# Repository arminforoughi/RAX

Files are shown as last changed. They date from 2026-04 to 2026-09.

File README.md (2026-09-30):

# RAX

**Pick up any object a camera can see, with no training.**

RAX drives a low-cost arm with a wrist camera to an object, lines the object up
between the jaws, squares the grip to it, and grasps. It needs the arm's URDF, a wrist
camera and a detector: a colour, or a text prompt through an open-vocabulary model.
There are no demonstrations, no learned policy and no hand-tuned signs.

On an SO-101 sorting lab tubes into racks, it picks about 80% of the tubes it maps and
stands about half of them upright in a 1 mm-clearance hole. Every run is logged as a
self-labelled episode.

Project page: https://arminforoughi.github.io/RAX/

## How it works

The pick is visual servoing on the arm's own kinematic model. It repeats one short
loop:

1. **See.** The detector gives the object's pixel. The error is how far that pixel is
   from where the fingertips will land, projected into the same image.
2. **Measure.** A small test turn of the base shows how many pixels the object moves
   per degree, so the correction is `error / gain`. No sign or scale is assumed; on the
   SO-101 the base turns the opposite way to intuition, and a hard-coded sign drove it
   steadily away from the object.
3. **Solve.** Every move is inverse kinematics on the URDF with the hand's angle held,
   started from several poses, keeping the solution nearest the current one.

In order: LOOK, PROBE, AIM, APPROACH, HOVER, STAND, TRIM, TWIST, DESCEND, GRASP, LIFT.
The image only ever turns the base. The reach comes from casting the pixel onto the
table, and then from a measured pixels-per-metre once the hand is over the object. The
last centimetres are a straight vertical drop, so the fingers never sweep the object
away. The grip is judged by where the jaws stop: shut means empty, stopped short means
holding, and too wide means it took two.

## Use it

```python
from rax.pick import pick, place, scan, ColourTarget, PromptTarget, TOP, SIDE

target = PromptTarget(prompt="cup", grasp_z=0.04)      # or ColourTarget(colours=("red",))
for obj in scan(arm, target):                          # map the table once
    pick(arm, target, near_xy=(obj.x, obj.y), grasp=TOP)   # TOP: 90deg down, SIDE: level
    place(arm, (0.20, -0.15), release_z=0.08, pitch=0, roll=90)
```

`arm` is anything that implements [`rax.pick.arm.Arm`](src/rax/pick/arm.py), about
fifteen methods: joints, FK, IK, a camera frame, pixel-to-table and back, the gripper.
[`rax.robots.so101.So101`](src/rax/robots/so101.py) is the real SO-101 with a wrist
OAK-D.

### No robot? Run the simulator

```
pip install -e .
python examples/pick_demo.py
```

[`rax.pick.sim.SimArm`](src/rax/pick/sim.py) uses the SO-101's real URDF, IK and camera
model, with a drawn image and a simple gripper, so the whole loop runs closed on a
laptop. It tests the logic, not the camera.

### The tube-sorting rig

```
pip install -e ".[robot]"
python examples/tube_sorting/server.py --port COM4      # UI on http://127.0.0.1:8486
```

It maps the mat with one wrist-camera sweep, picks each tube, stands it up and drops it
into its colour's rack. An optional overhead camera lines the tube up over the hole and
checks that it went in. See [`examples/tube_sorting`](examples/tube_sorting).

## Layout

```
src/rax/pick/         the method: pick, place, scan, targets, simulator, episodes
src/rax/kinematics/   URDF forward kinematics, pitch-holding IK, smooth moves
src/rax/perception/   camera model (pixels <-> base frame), tube-cap detector
src/rax/robots/       SO-101 driver, profile and URDF
examples/             pick_demo.py (simulator), tube_sorting/ (the real rig)
tests/                pytest; no hardware needed
```

## License

See [LICENSE](LICENSE).

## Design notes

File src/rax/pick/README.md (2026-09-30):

# rax.pick

Pick up any object a wrist camera can detect, with no training and no hand-tuned
signs. It needs the arm's URDF, a wrist camera, and a detector for the object.

```python
from rax.pick import pick, place, scan, PromptTarget, TOP, SIDE

cup = PromptTarget(prompt="cup", grasp_z=0.04)        # open-vocabulary, no training
for obj in scan(arm, cup):                            # map the table once
    pick(arm, cup, near_xy=(obj.x, obj.y), grasp=SIDE)
    place(arm, (0.20, -0.15), release_z=0.06, pitch=0, roll=0)
```

## How it works

The pick is visual servoing on the arm's own model:

1. **See.** The detector gives a pixel. The error is how far that pixel is from where
   the fingertips will land, projected into the same image.
2. **Measure.** A small test turn of the base shows how many pixels the object moves
   per degree. Dividing the error by that gives the correction, so no sign or scale is
   ever assumed.
3. **Solve.** Every move is inverse kinematics on the URDF with the hand's angle held,
   started from several poses, keeping the solution nearest the current one.

The stages are LOOK, PROBE, AIM, APPROACH, HOVER, STAND, TRIM, TWIST, DESCEND, GRASP
and LIFT (see `pick.py`). The image only ever turns the base. The reach comes from
casting the pixel onto the table, and then from a measured pixels-per-metre once the
hand is over the object.

**Grasp angle.** `TOP` comes straight down (pitch 90) and rolls the wrist square to the
object's long axis. `SIDE` keeps the hand level (pitch 0) and reaches in horizontally.

**Grip check.** The grip is judged by where the jaws stop: closed means empty, stopped
short means holding, and too wide means it took two.

## Plugging in

- **A robot:** implement `rax.pick.arm.Arm`, about fifteen methods covering joints, FK,
  IK, camera frame, cast and project, gripper, and log.
  `rax.robots.so101.So101` does it for the SO-101 with a wrist OAK-D.
- **An object:** subclass `Target` and write `detect()`. `ColourTarget` finds HSV blobs
  (test-tube caps). `PromptTarget` uses YOLO-World with a text prompt.

## Try it without a robot

```
python examples/pick_demo.py
```

`rax.pick.sim.SimArm` is the SO-101's real kinematics and camera model with a drawn
image and a simple gripper, so the full loop runs closed on a laptop. The sim tests the
logic, not the camera: a real run is the only real test.

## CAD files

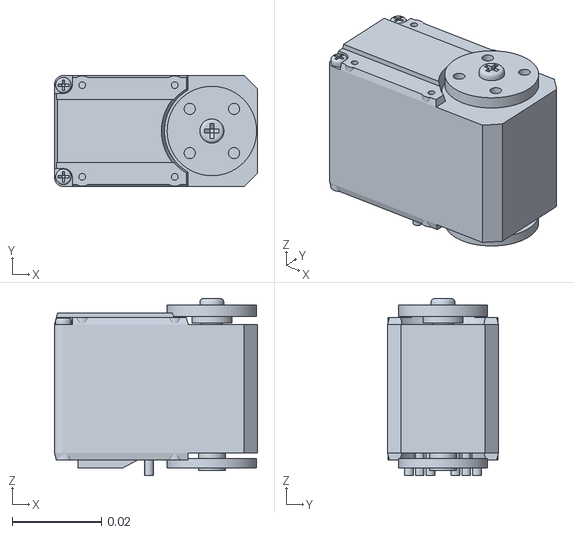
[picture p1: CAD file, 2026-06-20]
src/rax/robots/so101_model/assets/sts3215_03a_v1.stl
0.0454 x 0.0248 x 0.0396

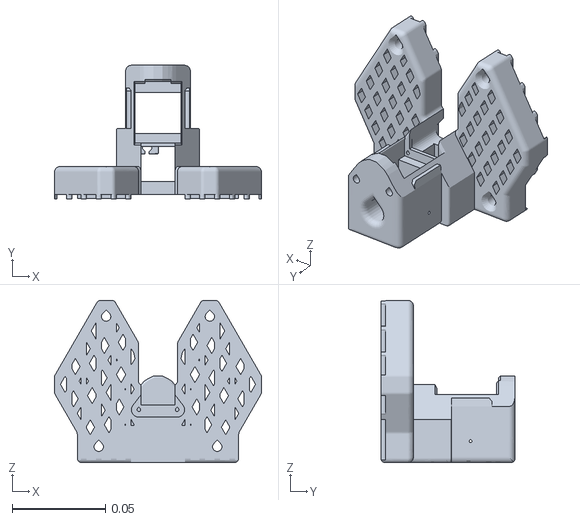
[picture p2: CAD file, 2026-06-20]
src/rax/robots/so101_model/assets/base_so101_v2.stl
0.111 x 0.072 x 0.087

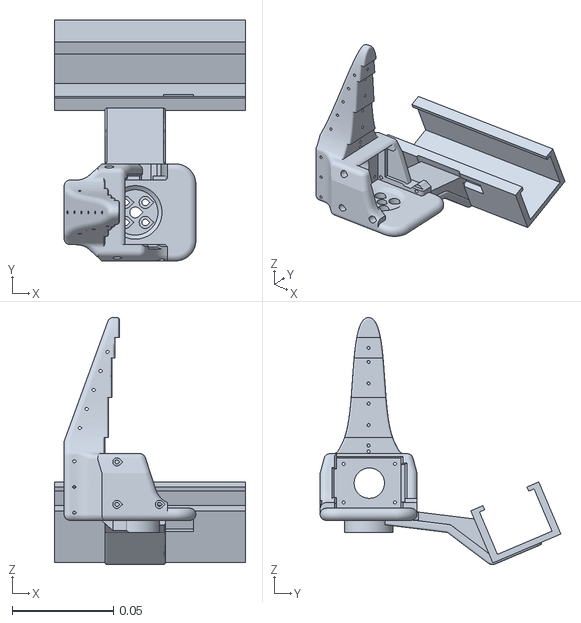
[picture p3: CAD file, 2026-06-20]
src/rax/robots/so101_model/assets/Wrist_Roll_D405_Holder - SO_ARM100_Wrist_Roll_2 v4.stl
0.0946 x 0.119 x 0.122

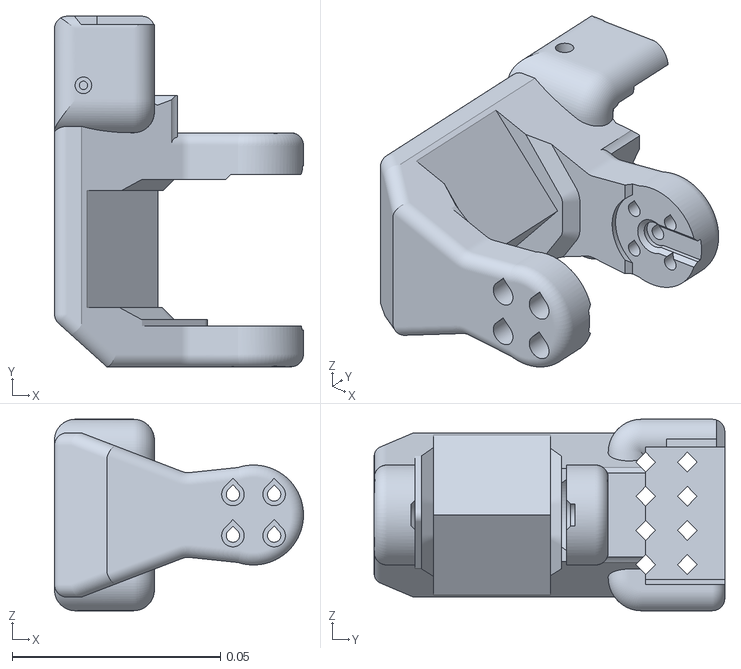
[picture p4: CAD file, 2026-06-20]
src/rax/robots/so101_model/assets/rotation_pitch_so101_v1.stl
0.0598 x 0.0842 x 0.046

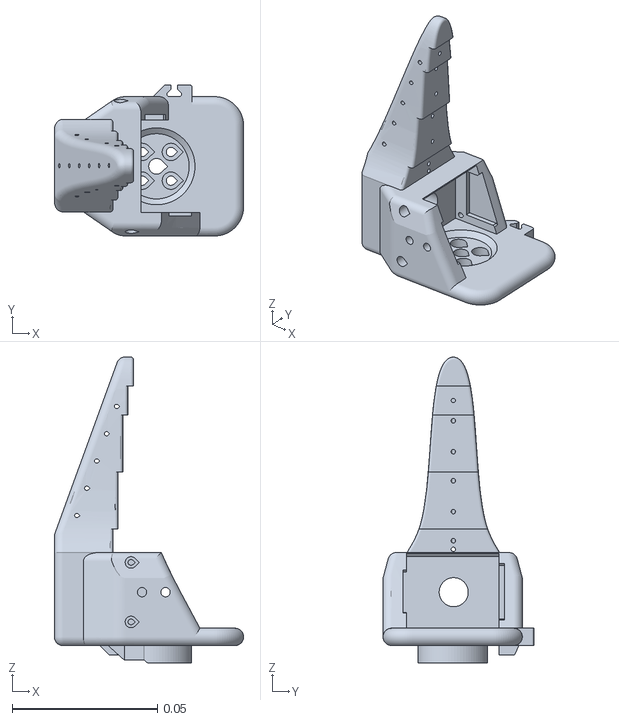
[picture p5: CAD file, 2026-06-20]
src/rax/robots/so101_model/assets/wrist_roll_follower_so101_v1.stl
0.0652 x 0.052 x 0.105

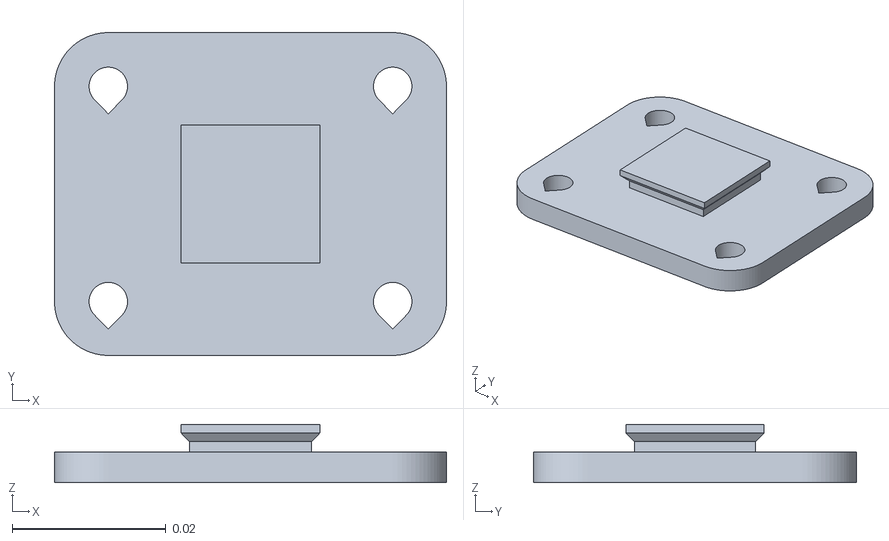
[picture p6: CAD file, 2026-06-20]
src/rax/robots/so101_model/assets/waveshare_mounting_plate_so101_v2.stl
0.051 x 0.042 x 0.0076

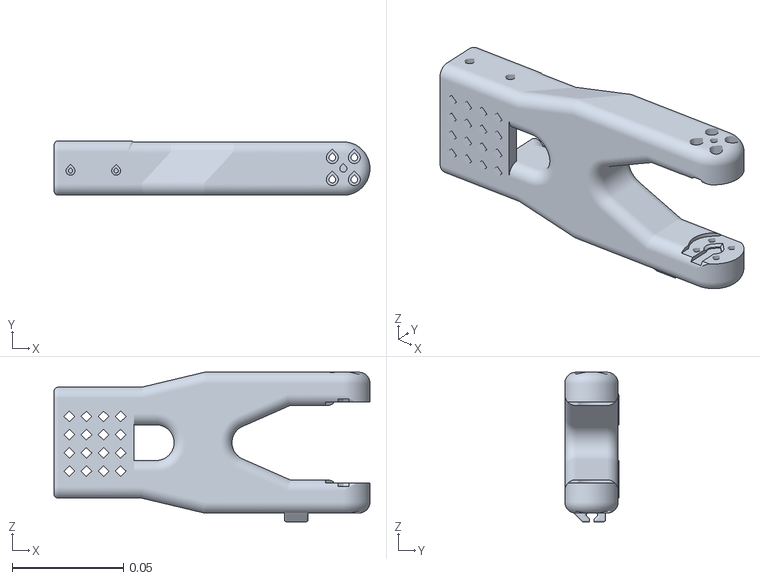
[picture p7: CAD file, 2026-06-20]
src/rax/robots/so101_model/assets/upper_arm_so101_v1.stl
0.142 x 0.0245 x 0.0673

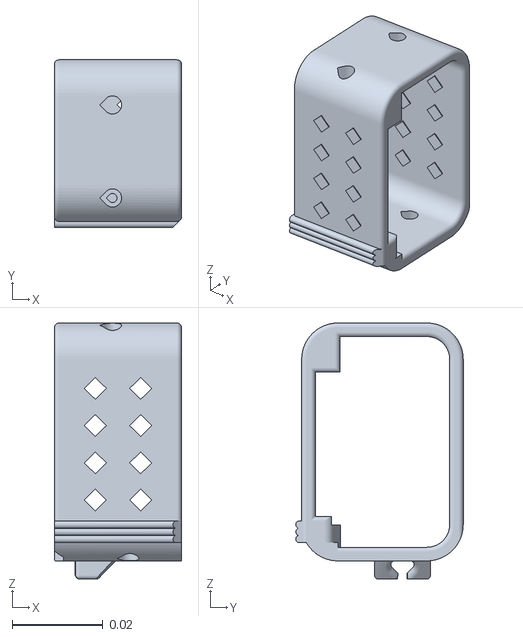
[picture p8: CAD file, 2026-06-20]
src/rax/robots/so101_model/assets/motor_holder_so101_wrist_v1.stl
0.028 x 0.0369 x 0.0564

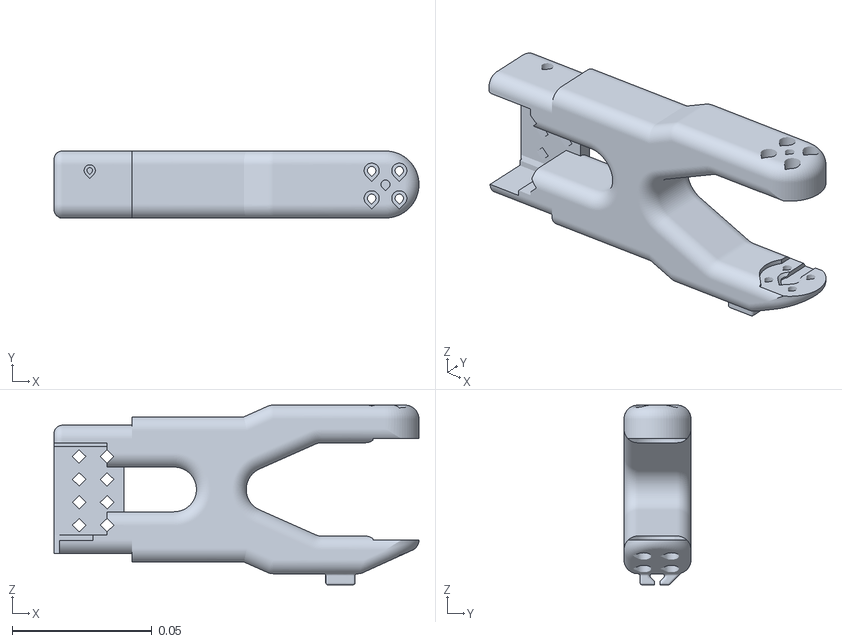
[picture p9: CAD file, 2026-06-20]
src/rax/robots/so101_model/assets/under_arm_so101_v1.stl
0.131 x 0.024 x 0.0644

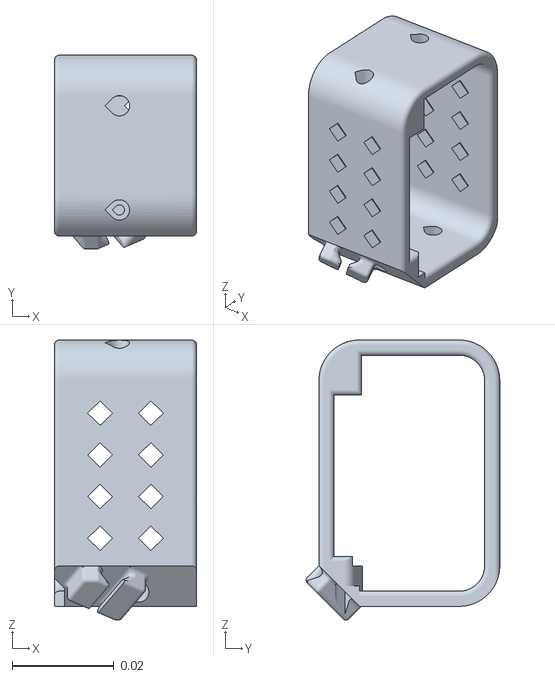
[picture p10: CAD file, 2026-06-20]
src/rax/robots/so101_model/assets/motor_holder_so101_base_v1.stl
0.028 x 0.0381 x 0.0551

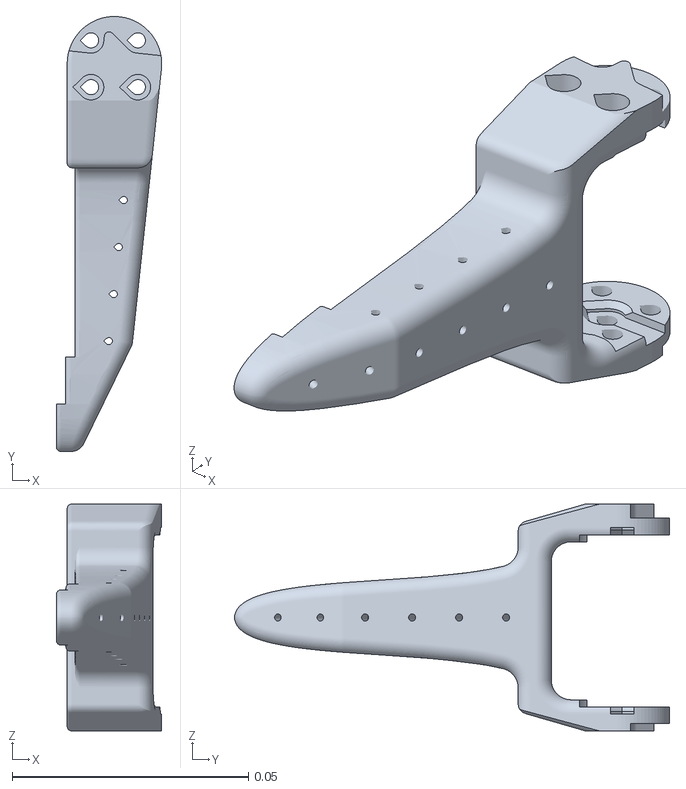
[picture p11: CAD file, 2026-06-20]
src/rax/robots/so101_model/assets/moving_jaw_so101_v1.stl
0.0223 x 0.092 x 0.048

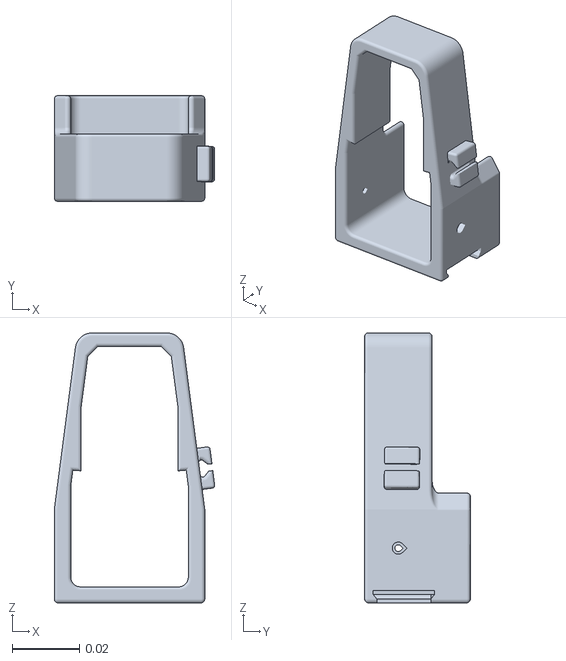
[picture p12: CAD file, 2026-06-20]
src/rax/robots/so101_model/assets/base_motor_holder_so101_v1.stl
0.0476 x 0.0314 x 0.0802

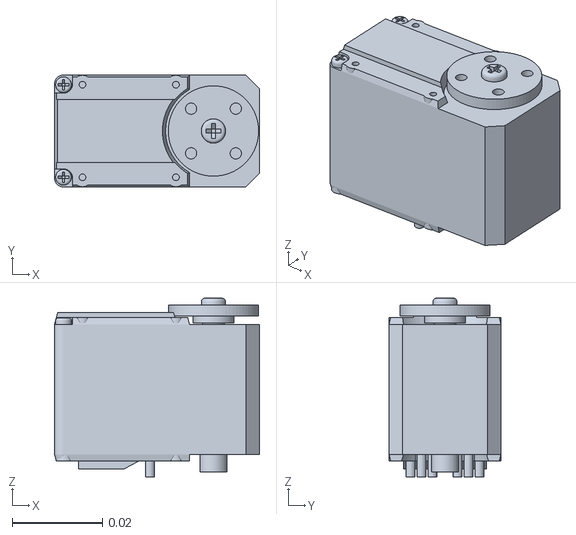
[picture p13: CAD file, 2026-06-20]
src/rax/robots/so101_model/assets/sts3215_03a_no_horn_v1.stl
0.0454 x 0.0248 x 0.0396

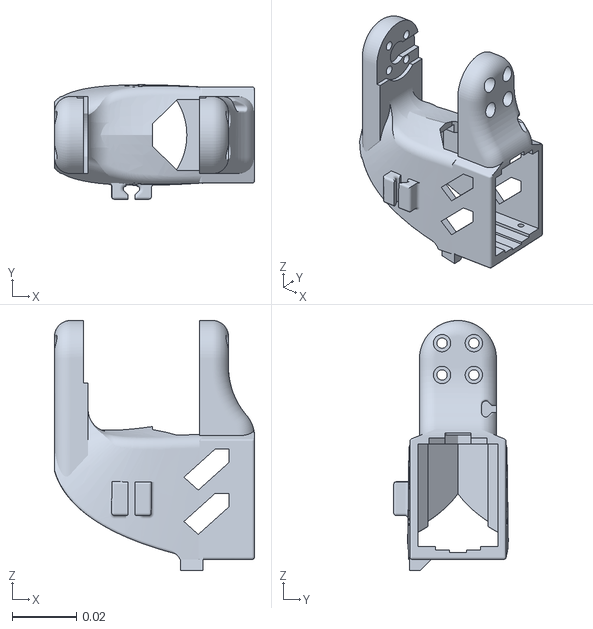
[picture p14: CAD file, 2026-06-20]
src/rax/robots/so101_model/assets/wrist_roll_pitch_so101_v2.stl
0.0623 x 0.0357 x 0.0778

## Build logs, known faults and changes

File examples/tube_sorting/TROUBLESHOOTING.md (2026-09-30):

# Mission server: the rig will not connect

Read this before touching a cable. In Sep 2026 this cost about a week, and the
whole time the hardware was fine.

## The symptom

`run_server.ps1` starts, the arm connects, and then the server dies:

```
overload cleared - 1:0x00 2:0x00 3:0x00 4:0x00 5:0x00 6:0x00   <- arm is FINE
connecting robot + camera...
WARNING [OAK-D] USB3 connect attempt 1 failed (Failed to find device after booting,
                error message: X_LINK_DEVICE_NOT_FOUND)
... 6 attempts, 3x USB3 then 3x USB2, ~17s each ...
RuntimeError: Failed to find device after booting, error message: X_LINK_DEVICE_NOT_FOUND
```

`X_LINK_DEVICE_NOT_FOUND` reads like "no camera attached". It is not. It means
the camera booted and then vanished before depthai could reopen it.

## Why it is so easy to misdiagnose

**The OAK-D has two USB identities.** This is the single most important fact here.

| id | name | when |
|---|---|---|
| `03E7:2485` | Movidius MyriadX | while idle, unbooted (bootloader) |
| `03E7:F63B` | Luxonis Device | after depthai uploads firmware |

`dai.Device()` boots the camera from `2485` into `F63B`, and `F63B` must
re-enumerate as a fresh USB device before depthai can open it. So a fault that
only affects `F63B` is **invisible at rest**: Device Manager shows a healthy
`Movidius MyriadX`, `getAllAvailableDevices()` returns the device with
`state=X_LINK_UNBOOTED, status=X_LINK_SUCCESS`, and everything looks correct
right up until you try to use it.

It also means **the camera works perfectly on another machine.** Both faults
below live in this PC's registry, keyed to the device. They do not travel with
the hardware. A successful test on a Mac tells you nothing about them - it only
rules out the camera, which was never the problem.

## The two root causes

### 1. The booted identity was disabled

`ConfigFlags=1` (`CONFIGFLAG_DISABLED`) on the `F63B` key. Windows disabled the
device the instant it enumerated. Watching the device tree once per second
during a connect attempt showed the whole cycle:

```
 0s  2485 bootloader   OK/present
 2s  2485 disappears                  <- device resets to boot
 3s  F63B appears      Error/present  <- booted, enumerated, then DISABLED
 8s  F63B still        Error/present
 9s  F63B gone, 2485 back             <- gives up, reverts to bootloader
```

The boot works every time. The device is disabled on arrival.

### 2. usbipd had the devices bound

Both the camera and the arm showed `STATE=Shared` in `usbipd list`, with the
OAK-D on the generic Microsoft `WINUSB` driver rather than a Luxonis one.
Binding hands a device toward WSL and swaps its driver.

Worse, these were **persisted** bindings, which re-apply themselves on every
replug. That is the mechanism that made the fault come back every single time
the camera was plugged in, no matter what was done to it.

## Diagnose

None of this needs admin:

```powershell
# is the booted identity disabled?  1 = CONFIGFLAG_DISABLED, 0 = healthy
(Get-ItemProperty 'HKLM:\SYSTEM\CurrentControlSet\Enum\USB\VID_03E7&PID_F63B\19443010F15FF81200' `
  -Name ConfigFlags).ConfigFlags

# is anything holding the devices?  look for STATE=Shared, and the Persisted list
usbipd list

# does the arm's port exist at all?
[System.IO.Ports.SerialPort]::getportnames()

# does the camera boot outside the server?  isolates depthai from lerobot/Flask
python -c "import depthai as dai; d=dai.Device(); print('OK', d.getUsbSpeed())"
```

To watch the boot cycle live, poll during a connect attempt:

```powershell
Get-PnpDevice | Where-Object { $_.InstanceId -match 'VID_03E7' } |
  Select-Object Status, Present, InstanceId
```

Note the busid in `usbipd list` **changes on every replug** (`5-3` one day, `5-2`
the next). Always read it fresh; a stale busid gives
`error: There is no device with busid`.

## Fix

Both need an **administrator** PowerShell. `Enable-PnpDevice` reports
`Generic failure` here because the `F63B` device is only present for ~6 seconds
during a boot attempt; the registry write is what actually lands.

```powershell
# 1. clear the disable flag
Set-ItemProperty 'HKLM:\SYSTEM\CurrentControlSet\Enum\USB\VID_03E7&PID_F63B\19443010F15FF81200' `
  -Name ConfigFlags -Value 0 -Type DWord

# 2. release both devices from usbipd (read busids fresh from 'usbipd list')
usbipd unbind --busid <camera-busid>
usbipd unbind --busid <arm-busid>
```

Then **unplug and replug the camera** so it re-enumerates with the flag clear.

`fix_oakd.ps1` (next to this file) does all of this in one pass, including taking ownership
of the `Enum` key if it refuses the write, and logs what it did.

Verify: `usbipd list` should show the rig as `Not shared` and, critically, the
`Persisted` section should no longer list the Movidius or the CH343. If a
persisted entry survives, the fault will return on the next replug.

## Prevention

`run_server.ps1` now preflights all three conditions before launching and
refuses to start with the exact remediation command, rather than dying ~40s
later inside `cam.connect()` with an error that reads like dead hardware.
`-SkipPreflight` bypasses it if a check ever misfires.

## Things that are NOT the cause

Ruled out during the investigation, recorded so nobody re-runs them:

- **Hubs / power.** Both devices sit behind two chained Genesys Logic hubs
  (`05E3:0610`), which is a genuinely plausible cause of exactly this failure -
  but the boot trace disproved it. The device re-enumerates cleanly every time.
- **The cable, the port, the camera.** It works on other machines.
- **depthai version.** 3.7.1, unchanged since Jun 2026, working before and after.
- **Process contention.** No Python process was running during the failures.
- **The server, lerobot, Flask.** Plain `dai.Device()` fails identically.
- **WSL holding the device.** Ubuntu was stopped, and no `/dev/ttyACM*` or
  `/dev/ttyUSB*` existed inside it.

## Related: the arm

The arm (`1A86:55D3`, CH343 -> COM4) fails differently and independently. If
`[System.IO.Ports.SerialPort]::getportnames()` returns **nothing**, the adapter
has not enumerated at all - that is a cable or port fault, and no config change
will help. Note `HKLM:\HARDWARE\DEVICEMAP\SERIALCOMM` does not exist when no
serial device is present; Windows creates it on demand, so a missing key means
"none attached", not "broken".

Do not confuse the two `Realtek RealManage COM1/COM2` devices for usable serial
ports. They are class `MultiFunction`, part of the board's IPMI/out-of-band
management, and they are always present.

## Related: the overhead camera

The server reads an optional overhead MJPEG camera (a CamSurv server) set by
`RAX_CAMSURV_URL`, `RAX_CAMSURV_PASSWORD` and `RAX_CAMSURV_STREAM`. Without it the drop
goes to each hole's estimated position and is not verified; the robot side is
unaffected. If the top view is blank, check whether anything is listening on that URL.

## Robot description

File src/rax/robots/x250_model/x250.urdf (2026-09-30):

<?xml version="1.0"?>
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
<robot name="x250">

  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

  <link name="base_link">
    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
  </link>

  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
  <link name="shoulder_link">
    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
  </link>

  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
  <link name="upper_arm_link">
    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
  </link>

  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
  <link name="forearm_link">
    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
  </link>

  <link name="wrist_link">
    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
  </link>

  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
  <link name="gripper_link">
    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
  </link>

  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
  <link name="gripper_frame_link"/>

  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
  <link name="left_finger_link">
    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
  </link>
  <link name="right_finger_link">
    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
  </link>

  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

  <joint name="base" type="revolute">
    <parent link="base_link"/>
    <child link="shoulder_link"/>
    <origin xyz="0 0 0.079" rpy="0 0 0"/>
    <axis xyz="0 0 1"/>
    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
    <limit lower="-3.059165" upper="3.222488" effort="10" velocity="3.0"/>
  </joint>

  <joint name="shoulder_2" type="revolute">
    <parent link="shoulder_link"/>
    <child link="upper_arm_link"/>
    <origin xyz="0 0 0.040" rpy="0 0 0"/>
    <axis xyz="0 1 0"/>
    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
    <limit lower="-1.840924" upper="1.504690" effort="10" velocity="3.0"/>
  </joint>

  <joint name="elbow" type="revolute">
    <parent link="upper_arm_link"/>
    <child link="forearm_link"/>
    <origin xyz="0.050 0 0.250" rpy="0 0 0"/>
    <axis xyz="0 1 0"/>
    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
    <limit lower="-0.944656" upper="0.936005" effort="10" velocity="3.0"/>
  </joint>

  <joint name="wrist" type="revolute">
    <parent link="forearm_link"/>
    <child link="wrist_link"/>
    <origin xyz="0.175 0 0" rpy="0 0 0"/>
    <axis xyz="0 1 0"/>
    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
    <limit lower="-1.641396" upper="4.640256" effort="10" velocity="3.0"/>
  </joint>

  <joint name="tool" type="revolute">
    <parent link="wrist_link"/>
    <child link="gripper_link"/>
    <origin xyz="0.075 0 0" rpy="0 0 0"/>
    <axis xyz="1 0 0"/>
    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
    <limit lower="-2.622260" upper="1.152868" effort="10" velocity="3.0"/>
  </joint>

  <joint name="ee_fixed" type="fixed">
    <parent link="gripper_link"/>
    <child link="gripper_frame_link"/>
    <origin xyz="0.080 0 0" rpy="0 0 0"/>
  </joint>

  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
  <joint name="gripper_left" type="prismatic">
    <parent link="gripper_link"/>
    <child link="left_finger_link"/>
    <origin xyz="0.050 0.013 0" rpy="0 0 0"/>
    <axis xyz="0 1 0"/>
    <limit lower="0.0" upper="0.022" effort="10" velocity="0.2"/>
  </joint>
  <joint name="gripper_right" type="prismatic">
    <parent link="gripper_link"/>
    <child link="right_finger_link"/>
    <origin xyz="0.050 -0.013 0" rpy="0 0 0"/>
    <axis xyz="0 -1 0"/>
    <limit lower="0.0" upper="0.022" effort="10" velocity="0.2"/>
  </joint>

</robot>

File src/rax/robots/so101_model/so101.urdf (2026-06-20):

<?xml version="1.0" encoding="utf-8"?>
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
<robot name="so101_new_calib">

  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
  <link name="base_link">
    <inertial>
      <origin xyz="0.0137179 -5.19711e-05 0.0334843" rpy="0 0 0"/>
      <mass value="0.147"/>
      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
    </inertial>
    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
  </link>

  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
  <link name="shoulder_link">
    <inertial>
      <origin xyz="-0.0307604 -1.66727e-05 -0.0252713" rpy="0 0 0"/>
      <mass value="0.100006"/>
      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
    </inertial>
    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
  </link>

  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
  <link name="upper_arm_link">
    <inertial>
      <origin xyz="-0.0898471 -0.00838224 0.0184089" rpy="0 0 0"/>
      <mass value="0.103"/>
      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
    </inertial>
    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
  </link>

  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
  <link name="lower_arm_link">
    <inertial>
      <origin xyz="-0.0980701 0.00324376 0.0182831" rpy="0 0 0"/>
      <mass value="0.104"/>
      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
    </inertial>
    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
  </link>

  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
  <link name="wrist_link">
    <inertial>
      <origin xyz="-0.000103312 -0.0386143 0.0281156" rpy="0 0 0"/>
      <mass value="0.079"/>
      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
    </inertial>
    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
  </link>

  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
  <link name="gripper_link">
    <inertial>
      <origin xyz="0.000213627 0.000245138 -0.025187" rpy="0 0 0"/>
      <mass value="0.087"/>
      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
    </inertial>
    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
  </link>

  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
  <link name="gripper_frame_link">
    <origin xyz="0 0 0" rpy="0 -0 0"/>
    <inertial>
      <origin xyz="0 0 0" rpy="0 0 0"/>
      <mass value="1e-9"/>
      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
    </inertial>
  </link>

  <joint name="gripper_frame_joint" type="fixed">
    <origin xyz="-0.0079 -0.000218121 -0.0981274" rpy="0 3.14159 0"/>
    <parent link="gripper_link"/>
    <child link="gripper_frame_link"/>
    <axis xyz="0 0 0"/>
  </joint>

  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
  <link name="moving_jaw_so101_v1_link">
    <inertial>
      <origin xyz="-0.00157495 -0.0300244 0.0192755" rpy="0 0 0"/>
      <mass value="0.012"/>
      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
    </inertial>
    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
  </link>

  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
  <joint name="gripper" type="revolute">
    <origin xyz="0.0202 0.0188 -0.0234" rpy="1.5708 -5.24284e-08 -1.41553e-15"/>
    <parent link="gripper_link"/>
    <child link="moving_jaw_so101_v1_link"/>
    <axis xyz="0 0 1"/>
    <limit effort="10" velocity="10" lower="-0.174533" upper="1.74533"/>
  </joint>

  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
  <joint name="wrist_roll" type="revolute">
    <origin xyz="5.55112e-17 -0.0611 0.0181" rpy="1.5708 0.0486795 3.14159"/>
    <parent link="wrist_link"/>
    <child link="gripper_link"/>
    <axis xyz="0 0 1"/>
    <limit effort="10" velocity="10" lower="-2.74385" upper="2.84121"/>
  </joint>

  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
  <joint name="wrist_flex" type="revolute">
    <origin xyz="-0.1349 0.0052 3.62355e-17" rpy="4.02456e-15 8.67362e-16 -1.5708"/>
    <parent link="lower_arm_link"/>
    <child link="wrist_link"/>
    <axis xyz="0 0 1"/>
    <limit effort="10" velocity="10" lower="-1.65806" upper="1.65806"/>
  </joint>

  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
  <joint name="elbow_flex" type="revolute">
    <origin xyz="-0.11257 -0.028 1.73763e-16" rpy="-3.63608e-16 8.74301e-16 1.5708"/>
    <parent link="upper_arm_link"/>
    <child link="lower_arm_link"/>
    <axis xyz="0 0 1"/>
    <limit effort="10" velocity="10" lower="-1.69" upper="1.69"/>
  </joint>

  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
  <joint name="shoulder_lift" type="revolute">
    <origin xyz="-0.0303992 -0.0182778 -0.0542" rpy="-1.5708 -1.5708 0"/>
    <parent link="shoulder_link"/>
    <child link="upper_arm_link"/>
    <axis xyz="0 0 1"/>
    <limit effort="10" velocity="10" lower="-1.74533" upper="1.74533"/>
  </joint>

  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
  <joint name="shoulder_pan" type="revolute">
    <origin xyz="0.0388353 -8.97657e-09 0.0624" rpy="3.14159 4.18253e-17 -3.14159"/>
    <parent link="base_link"/>
    <child link="shoulder_link"/>
    <axis xyz="0 0 1"/>
    <limit effort="10" velocity="10" lower="-1.91986" upper="1.91986"/>
  </joint>

  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 

</robot>

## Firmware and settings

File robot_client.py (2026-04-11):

#!/usr/bin/env python3
"""
Robot Client — runs on the Booster K1 robot.
Streams camera + depth + audio to a remote server via WebSocket.
Receives and executes control commands.

Usage:
    python3 robot_client.py eth0 --server ws://YOUR_PC_IP:9090
"""

import os
import sys
import glob
import asyncio
import threading
import time
import argparse
import json
import struct
import zlib

import numpy as np
import cv2
try:
    import pyaudio
except ImportError:
    import pyaudio_compat as pyaudio
import websockets

import rclpy
from rclpy.node import Node
from sensor_msgs.msg import Image, CompressedImage
from cv_bridge import CvBridge

from booster_robotics_sdk_python import (
    B1LocoClient, ChannelFactory, RobotMode, B1HandIndex, B1HandAction,
    Position, Orientation, Posture,
)

SEND_SAMPLE_RATE = 16000
RECV_SAMPLE_RATE = 24000
AUDIO_CHANNELS = 1
AUDIO_FORMAT = pyaudio.paInt16
AUDIO_CHUNK = 1024

# Binary message type prefixes (robot -> server stream)
MSG_VIDEO = 0x01
MSG_DEPTH = 0x02
MSG_AUDIO_IN = 0x03

# Optional low-level joint API (fight guard / jabs use real elbow/shoulder angles).
_LOWLEVEL = None
try:
    import booster_robotics_sdk_python as _br_sdk
    _b1 = getattr(_br_sdk, 'b1', None)
    _LOWLEVEL = {
        'B1LowStateSubscriber': getattr(_br_sdk, 'B1LowStateSubscriber', None),
        'B1LowCmdPublisher': getattr(_br_sdk, 'B1LowCmdPublisher', None),
        'LowCmd': getattr(_br_sdk, 'LowCmd', None),
        'MotorCmd': getattr(_br_sdk, 'MotorCmd', None),
        'CmdType': getattr(_br_sdk, 'CmdType', None),
        'JointIndex': getattr(_br_sdk, 'JointIndex', None),
        'kTopicJointCtrl': getattr(_br_sdk, 'kTopicJointCtrl', None) or (
            getattr(_b1, 'kTopicJointCtrl', None) if _b1 else None
        ),
        'kJointCnt': getattr(_br_sdk, 'kJointCnt', None),
    }
    if not all((_LOWLEVEL['B1LowStateSubscriber'], _LOWLEVEL['B1LowCmdPublisher'],
                _LOWLEVEL['LowCmd'], _LOWLEVEL['MotorCmd'], _LOWLEVEL['JointIndex'])):
        _LOWLEVEL = None
except ImportError:
    _LOWLEVEL = None


def _prepend_booster_interface_paths():
    """Find booster_interface Python bindings without sourcing setup.bash (systemd / wrong cwd)."""
    added = []
    seen = set(sys.path)

    def _add(sp):
        sp = os.path.abspath(sp)
        if not os.path.isdir(sp) or sp in seen:
            return
        bi = os.path.join(sp, 'booster_interface')
        if not os.path.isdir(bi):
            return
        sys.path.insert(0, sp)
        seen.add(sp)
        added.append(sp)

    roots = []
    for key in ('BOOSTER_ROS2_INSTALL', 'COLCON_PREFIX_PATH'):
        raw = os.environ.get(key, '')
        for part in raw.split(os.pathsep):
            part = part.strip()
            if not part:
                continue
            roots.append(part)
            if not part.rstrip(os.sep).endswith('install') and os.path.isdir(os.path.join(part, 'install')):
                roots.append(os.path.join(part, 'install'))

    roots.extend([
        '/opt/booster/BoosterRos2Interface/install',
        '/opt/booster/ros2_ws/install',
    ])

    for base in roots:
        if not base or not os.path.isdir(base):
            continue
        pattern = os.path.join(base, 'booster_interface', 'lib', 'python*', 'site-packages')
        for sp in glob.glob(pattern):
            _add(sp)

    for prefix in os.environ.get('AMENT_PREFIX_PATH', '').split(os.pathsep):
        prefix = prefix.strip()
        if not prefix or not os.path.isdir(prefix):
            continue
        for sp in glob.glob(os.path.join(prefix, 'lib', 'python*', 'site-packages')):
            _add(sp)

    # Shallow walk: install layout on K1 often differs from the paths above.
    for root, max_depth in (
        ('/opt/booster', 10),
        (os.path.expanduser('~/booster_ws/install'), 8),
        (os.path.expanduser('~/ros2_ws/install'), 8),
    ):
        if not root or not os.path.isdir(root):
            continue
        root = os.path.abspath(root)
        for dirpath, dirnames, _ in os.walk(root):
            depth = dirpath[len(root) :].count(os.sep)
            if depth > max_depth:
                dirnames[:] = []
                continue
            if os.path.basename(dirpath) == 'site-packages' and os.path.isdir(
                os.path.join(dirpath, 'booster_interface')
            ):
                _add(dirpath)

    return added


def _ji(joint_index_enum, name):
    """Safe JointIndex lookup (int value for motor_cmd index)."""
    if joint_index_enum is None:
        return None
    j = getattr(joint_index_enum, name, None)
    if j is None:
        return None
    try:
        return int(j)
    except (TypeError, ValueError):
        return j


def _joint_index_enum():
    """JointIndex for arm mapping (SDK may expose it even when DDS lowcmd is unused)."""
    if _LOWLEVEL and _LOWLEVEL.get('JointIndex'):
        return _LOWLEVEL['JointIndex']
    try:
        import booster_robotics_sdk_python as _br
        return getattr(_br, 'JointIndex', None)
    except ImportError:
        return None


class FightLowCmdController:
    """LowCmd fight control: ROS2 joint_ctrl + /low_state (Booster deploy), else DDS LowCmd."""

    def __init__(self, loco_client: B1LocoClient, sdk_lock: threading.Lock, ros_node=None):
        self.client = loco_client
        self.sdk_lock = sdk_lock
        self._ros_node = ros_node
        self._use_ros = False
        self._q = None
        self._q_lock = threading.Lock()
        self._pub = None
        self._sub = None
        self._n = 0
        self._hold = threading.Event()
        self._hold_thread = None
        self._hz = 50.0
        self._kp_default = 55.0
        self._kd_default = 2.2
        self._kp_arm = 72.0
        self._kd_arm = 2.8
        self._guard_ov = {}
        self._overlay = {}
        self._overlay_lock = threading.Lock()

    @staticmethod
    def _booster_ros_msgs_ok():
        try:
            from booster_interface.msg import LowCmd  # noqa: F401
            return True
        except ImportError:
            return False

    @property
    def available(self):
        # Always try if we have the streaming node (it will import booster_interface on demand).
        if self._ros_node is not None:
            return True
        return self._booster_ros_msgs_ok() or _LOWLEVEL is not None

    def set_ros_node(self, node):
        self._ros_node = node

    def _on_state(self, msg):
        try:
            serial = msg.motor_state_serial
            with self._q_lock:
                self._q = [float(m.q) for m in serial]
                self._n = len(self._q)
        except Exception:
            pass

    def _get_base_q(self):
        if self._use_ros and self._ros_node is not None:
            q = self._ros_node.booster_joint_snapshot()
            if q and len(q) == self._n:
                return q
            return None
        with self._q_lock:
            return list(self._q) if self._q else None

    def _ensure_io(self):
        if self._n > 0 and (self._use_ros or self._pub is not None):
            return True

        if self._ros_node is not None:
            if self._ros_node.ensure_booster_fight_bridge():
                t0 = time.time()
                while time.time() - t0 < 3.0:
                    n = self._ros_node.booster_num_joints()
                    if n > 0:
                        break
                    time.sleep(0.02)
                n = self._ros_node.booster_num_joints()
                if n <= 0:
                    print('[FightLowCmd] /low_state not received (check Booster ROS2 bridge)')
                else:
                    self._ros_node.booster_init_lowcmd_motors(n)
                    if self._ros_node.booster_wait_joint_ctrl_subscriber(25.0):
                        self._n = n
                        self._use_ros = True
                        print('[FightLowCmd] ROS2 joint_ctrl + /low_state (same as booster_deploy / teleop stack)')
                        return True
                    print('[FightLowCmd] No subscriber on joint_ctrl yet (motion stack listening?)')
                    self._n = 0

        if _LOWLEVEL is None:
            return False
        L = _LOWLEVEL
        topic = L['kTopicJointCtrl'] or 'rt/low_cmd'
        try:
            self._sub = L['B1LowStateSubscriber'](self._on_state)
            self._sub.InitChannel()
        except Exception as e:
            print(f"[FightLowCmd] DDS LowState subscriber failed: {e}")
            return False
        topics = []
        for t in (topic, 'rt/low_cmd', 'rt/joint_ctrl'):
            if t and t not in topics:
                topics.append(t)
        self._pub = None
        last_err = None
        for tp in topics:
            try:
                pub = L['B1LowCmdPublisher'](tp)
                pub.InitChannel()
                self._pub = pub
                break
            except Exception as e:
                last_err = e
        if self._pub is None:
            try:
                self._pub = L['B1LowCmdPublisher']()
                self._pub.InitChannel()
            except Exception as e:
                print(f"[FightLowCmd] DDS LowCmd publisher failed ({last_err or e})")
                return False
        t0 = time.time()
        while self._n == 0 and time.time() - t0 < 2.5:
            time.sleep(0.02)
        if self._n > 0:
            print('[FightLowCmd] DDS LowCmd publisher (fallback)')
        return self._n > 0

    def _cmd_type(self):
        L = _LOWLEVEL
        ct = L['CmdType']
        if ct is None:
            return None
        return getattr(ct, 'SERIAL', None) or getattr(ct, 'PARALLEL', None)

    def _write_lowcmd(self, q_targets, arm_idx_set):
        """Publish one frame: position hold on all joints to q_targets."""
        if self._use_ros and self._ros_node is not None:
            mcs = self._ros_node._bf_motor_cmd
            for i in range(self._n):
                q = q_targets[i]
                kp = self._kp_arm if i in arm_idx_set else self._kp_default
                kd = self._kd_arm if i in arm_idx_set else self._kd_default
                mcs[i].q = q
                mcs[i].dq = 0.0
                mcs[i].tau = 0.0
                mcs[i].kp = kp
                mcs[i].kd = kd
                mcs[i].weight = 1.0
            self._ros_node.booster_publish_lowcmd()
            return True

        L = _LOWLEVEL
        LowCmd, MotorCmd = L['LowCmd'], L['MotorCmd']
        msg = LowCmd()
        ct = self._cmd_type()
        if ct is not None:
            try:
                msg.cmd_type = ct
            except Exception:
                try:
                    msg.cmd_type(ct)
                except Exception:
                    pass
        motors = []
        for i in range(self._n):
            mc = MotorCmd()
            q = q_targets[i]
            kp = self._kp_arm if i in arm_idx_set else self._kp_default
            kd = self._kd_arm if i in arm_idx_set else self._kd_default
            for attr, val in (('q', q), ('dq', 0.0), ('tau', 0.0), ('kp', kp), ('kd', kd), ('weight', 1.0)):
                try:
                    setattr(mc, attr, val)
                except Exception:
                    try:
                        getattr(mc, attr)(val)
                    except Exception:
                        pass
            motors.append(mc)
        try:
            msg.motor_cmd = motors
        except Exception:
            try:
                for m in motors:
                    msg.motor_cmd.append(m)
            except Exception:
                return False
        try:
            if hasattr(self._pub, 'Write'):
                self._pub.Write(msg)
            elif hasattr(self._pub, 'write'):
                self._pub.write(msg)
            elif hasattr(self._pub, 'Publish'):
                self._pub.Publish(msg)
            else:
                return False
        except Exception as e:
            print(f"[FightLowCmd] Write failed: {e}")
            return False
        return True

    def _blend(self, a, b, alpha):
        return [a[i] + (b[i] - a[i]) * alpha for i in range(len(a))]

    def _arm_indices(self):
        J = _joint_index_enum()
        idx = []
        for name in (
            'kLeftShoulderPitch', 'kLeftShoulderRoll', 'kLeftElbowPitch', 'kLeftElbowYaw',
            'kRightShoulderPitch', 'kRightShoulderRoll', 'kRightElbowPitch', 'kRightElbowYaw',
        ):
            v = _ji(J, name)
            if v is not None and v < self._n:
                idx.append(v)
        return set(idx)

    def guard_targets(self):
        """Joint radians: arms up in guard (shoulders forward/up, elbows clearly bent)."""
        J = _joint_index_enum()
        t = {}
        # Tunable on-robot; signs follow Booster B1-style layout.
        t[_ji(J, 'kLeftShoulderPitch')] = 0.82
        t[_ji(J, 'kLeftShoulderRoll')] = 0.58
        t[_ji(J, 'kLeftElbowPitch')] = 1.72
        t[_ji(J, 'kLeftElbowYaw')] = -0.08
        t[_ji(J, 'kRightShoulderPitch')] = 0.82
        t[_ji(J, 'kRightShoulderRoll')] = -0.58
        t[_ji(J, 'kRightElbowPitch')] = 1.72
        t[_ji(J, 'kRightElbowYaw')] = 0.08
        return {k: v for k, v in t.items() if k is not None}

    def punch_delta(self, hand):
        J = _joint_index_enum()
        if hand == 'left':
            return {
                _ji(J, 'kLeftShoulderPitch'): 0.42,
                _ji(J, 'kLeftElbowPitch'): -0.82,
            }
        return {
            _ji(J, 'kRightShoulderPitch'): 0.42,
            _ji(J, 'kRightElbowPitch'): -0.82,
        }

    def punch_peak_overrides(self, hand):
        """Absolute arm targets = guard + punch delta (elbow extends, shoulder drives forward)."""
        out = dict(self._guard_ov)
        for k, dv in self.punch_delta(hand).items():
            if k is not None and k in out:
                out[k] = out[k] + dv
        return out

    def set_overlay(self, d):
        with self._overlay_lock:
            self._overlay = dict(d) if d else {}

    def clear_overlay(self):
        with self._overlay_lock:
            self._overlay = {}

    def _apply_overrides(self, base_q, overrides):
        out = list(base_q)
        for idx, val in overrides.items():
            if idx is not None and 0 <= idx < len(out):
                out[idx] = val
        return out

    def run_hold_loop(self, arm_idx_set):
        """Hold loop: legs/head track measured q; arms use guard + optional punch overlay."""
        period = 1.0 / self._hz
        while self._hold.is_set():
            base = self._get_base_q()
            if not base or len(base) != self._n:
                time.sleep(period)
                continue
            with self._overlay_lock:
                ov = {**self._guard_ov, **self._overlay}
            tgt = self._apply_overrides(base, ov)
            self._write_lowcmd(tgt, arm_idx_set)
            time.sleep(period)

    def interpolate_to(self, target_overrides, arm_idx_set, duration_s=0.65):
        start = self._get_base_q()
        if not start or len(start) != self._n:
            return False
        end = self._apply_overrides(start, target_overrides)
        steps = max(1, int(duration_s * self._hz))
        for s in range(1, steps + 1):
            if not self._hold.is_set():
                break
            a = s / steps
            blended = self._blend(start, end, a)
            self._write_lowcmd(blended, arm_idx_set)
            time.sleep(1.0 / self._hz)
        return True

    def enter_custom_and_stream(self, guard_overrides, arm_idx_set):
        Custom = (
            getattr(RobotMode, 'kCustom', None)
            or getattr(RobotMode, 'k_Manual', None)
            or getattr(RobotMode, 'kDevelop', None)
        )
        if Custom is None:
            print('[FightLowCmd] No Custom/manual RobotMode — cannot use low-level fight')
            return False
        try:
            with self.sdk_lock:
                self.client.SwitchHandEndEffectorControlMode(False)
        except Exception:
            pass

        # Booster deploy order: seed LowCmd from measured q, publish, sleep, then Custom.
        if self._use_ros:
            init = self._get_base_q()
            if not init or len(init) != self._n:
                print('[FightLowCmd] No joint snapshot for Custom startup')
                return False
            mcs = self._ros_node._bf_motor_cmd
            for i in range(self._n):
                mcs[i].q = init[i]
                kp = self._kp_arm if i in arm_idx_set else self._kp_default
                kd = self._kd_arm if i in arm_idx_set else self._kd_default
                mcs[i].dq = 0.0
                mcs[i].tau = 0.0
                mcs[i].kp = kp
                mcs[i].kd = kd
                mcs[i].weight = 1.0
            self._ros_node.booster_publish_lowcmd()
            time.sleep(0.1)
            try:
                with self.sdk_lock:
                    self.client.ChangeMode(Custom)
                time.sleep(0.05)
            except Exception as e:
                print(f"[FightLowCmd] ChangeMode(Custom) failed: {e}")
                return False
        else:
            try:
                with self.sdk_lock:
                    self.client.ChangeMode(Custom)
                time.sleep(0.05)
            except Exception as e:
                print(f"[FightLowCmd] ChangeMode(Custom) failed: {e}")
                return False

        self._guard_ov = dict(guard_overrides)
        with self._overlay_lock:
            self._overlay = {}
        self._hold.set()
        if not self.interpolate_to(guard_overrides, arm_idx_set, duration_s=0.7):
            self._hold.clear()
            self._guard_ov = {}
            try:
                with self.sdk_lock:
                    self.client.ChangeMode(RobotMode.kPrepare)
                time.sleep(0.25)
                with self.sdk_lock:
                    self.client.ChangeMode(RobotMode.kWalking)
            except Exception:
                pass
            print('[FightLowCmd] No LowState yet — cannot hold Custom pose')
            return False

        def _loop():
            self.run_hold_loop(arm_idx_set)

        self._hold_thread = threading.Thread(target=_loop, daemon=True)
        self._hold_thread.start()
        return True

    def stop_and_walk(self):
        self._hold.clear()
        if self._hold_thread and self._hold_thread.is_alive():
            self._hold_thread.join(timeout=1.5)
        self._hold_thread = None
        self._guard_ov = {}
        with self._overlay_lock:
            self._overlay = {}
        try:
            with self.sdk_lock:
                self.client.ChangeMode(RobotMode.kPrepare)
            time.sleep(0.35)
            with self.sdk_lock:
                self.client.ChangeMode(RobotMode.kWalking)
            time.sleep(0.15)
        except Exception as e:
            print(f"[FightLowCmd] return to Walking failed: {e}")


# ── ROS2 Camera Streamer ────────────────────────────────────────────────────
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

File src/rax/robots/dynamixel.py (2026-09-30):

"""Dynamixel protocol 2.0 over a serial port, with no SDK behind it.

WHY THIS EXISTS. The X250's servos speak protocol 2.0; the SO-101's speak Feetech, and
``scservo_sdk`` is the only servo SDK installed on the rig. Rather than add a dependency
to talk to six motors, the protocol is small enough to write down: a four-byte header, a
length, an instruction, a CRC, and a byte-stuffing rule. What follows is that, and
nothing else.

It is deliberately NOT a robot. It reads and writes registers on numbered ids. Which id
is the elbow, what a tick means in degrees, and whether a pose is safe are all questions
for :mod:`rax.robots.x250`, which is where the answers can be tested without a
serial port attached.

THE ONE SUBTLETY IS BYTE STUFFING. The header ``FF FF FD`` is what a device scans for,
so any payload that happens to contain it would resynchronise the receiver mid-packet.
Protocol 2.0 handles that by inserting an extra ``FD`` after any ``FF FF FD`` in the
payload, and the receiver removes it. Skip the stuffing and the bus works perfectly until
a goal position lands on the wrong value and the arm lunges -- so it is done here, in one
place, for every packet.
"""

from __future__ import annotations

import time
from dataclasses import dataclass

__all__ = [
    "DynamixelBus",
    "DynamixelError",
    "ADDR",
    "crc16",
]

#: Control-table addresses for the X-series (XM430 / XL430), as (address, length).
ADDR = {
    "torque_enable": (64, 1),
    "led": (65, 1),
    "goal_position": (116, 4),
    "moving_speed": (112, 4),
    "present_position": (132, 4),
    "present_velocity": (128, 4),
    "present_load": (126, 2),
    "hardware_error": (70, 1),
    "model_number": (0, 2),
}

_INSTR_PING = 0x01
_INSTR_READ = 0x02
_INSTR_WRITE = 0x03
_INSTR_STATUS = 0x55
_BROADCAST = 0xFE
_HEADER = b"\xff\xff\xfd\x00"


class DynamixelError(RuntimeError):
    """A servo did not answer, or answered with an error flag set."""


def crc16(data: bytes) -> int:
    """CRC-16/IBM-3740, the one protocol 2.0 specifies.

    Written out rather than table-driven: six motors at a few hundred packets a second
    is nowhere near the speed where a 256-entry table earns its place, and a loop is
    easier to check against the specification.
    """
    crc = 0
    for b in data:
        crc ^= b << 8
        for _ in range(8):
            crc = ((crc << 1) ^ 0x8005) & 0xFFFF if crc & 0x8000 else (crc << 1) & 0xFFFF
    return crc


def _stuff(payload: bytes) -> bytes:
    """Insert the extra 0xFD that stops a payload imitating the header."""
    out = bytearray()
    run = 0
    for b in payload:
        out.append(b)
        if run == 0 and b == 0xFF:
            run = 1
        elif run == 1 and b == 0xFF:
            run = 2
        elif run == 2 and b == 0xFD:
            out.append(0xFD)
            run = 0
        elif run == 2 and b == 0xFF:
            run = 2
        else:
            run = 1 if b == 0xFF else 0
    return bytes(out)


def _unstuff(payload: bytes) -> bytes:
    out = bytearray()
    i = 0
    while i < len(payload):
        out.append(payload[i])
        if (payload[i:i + 3] == b"\xff\xff\xfd" and i + 3 < len(payload)
                and payload[i + 3] == 0xFD):
            out.extend(payload[i + 1:i + 3])
            i += 4
            continue
        i += 1
    return bytes(out)


def build_packet(dxl_id: int, instruction: int, params: bytes = b"") -> bytes:
    """One protocol-2.0 instruction packet, stuffed and CRC'd."""
    p = _stuff(params)
    length = len(p) + 3                     # instruction + params + 2 CRC
    body = _HEADER + bytes([dxl_id & 0xFF, length & 0xFF, (length >> 8) & 0xFF,
                            instruction & 0xFF]) + p
    c = crc16(body)
    return body + bytes([c & 0xFF, (c >> 8) & 0xFF])


@dataclass
class Status:
    """One reply: which id sent it, its error byte, and the parameters."""

    dxl_id: int
    error: int
    params: bytes


def parse_statuses(buf: bytes) -> list[Status]:
    """Every complete status packet in a buffer, in order.

    Tolerates leading rubbish and partial trailing packets, because on a shared half
    duplex line both happen: the reply to the previous instruction can still be arriving,
    and a read can return mid-packet.
    """
    out: list[Status] = []
    i = 0
    while True:
        i = buf.find(_HEADER, i)
        if i < 0 or i + 9 > len(buf):
            break
        length = buf[i + 5] | (buf[i + 6] << 8)
        end = i + 7 + length
        if length < 4 or end > len(buf):
            break
        if buf[i + 7] == _INSTR_STATUS:
            body = buf[i:end - 2]
            got = buf[end - 2] | (buf[end - 1] << 8)
            if crc16(body) == got:
                out.append(Status(buf[i + 4], buf[i + 8],
                                  _unstuff(bytes(buf[i + 9:end - 2]))))
        i = end if end > i else i + 4
    return out
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

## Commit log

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2026-06-19 Model-based 3D gaze-grasp approach + detection hardening
    Rework the SO-101 gaze engine from an unstable 2D joint-pixel servo into a
    model-based Cartesian approach to the object's known 3D point (cloud centroid,
    base frame):
    - Servo the EE so the camera's aim ray lands on the object at grasp range along
    a selectable approach axis (topdown/horizontal/angled); placo IK solves all
    joints jointly, removing the pan/tilt cross-coupling that hunted in pitch.
    - Latch the object's 3D point from reliable views and commit once close, so the
    pick survives point-blank where stereo/mask degrade.
    - Ramp the image aim from centre down to the bottom-centre gripper line, and
    prioritise pointing until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
    [robot_client.py]
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2026-06-20 Add SO-101 URDF + STL meshes
    Vendor the kinematic model the driver loads by default
    (SO101/so101_new_calib.urdf) plus its STL meshes — placo fails to load the URDF
    without them, so the URDF alone is not enough. Lands the model at the driver's
    default relative path so the branch runs without the external lerobot checkout.
    [Wrist_Roll_D405_Holder - SO_ARM100_Wrist_Roll_2 v4.stl, base_motor_holder_so101_v1.stl, base_so101_v2.stl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]
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2026-06-28 Fix data_received callback signature and add audio playback
    - data_received now receives DataPacket object (not positional args)
    — was silently dropping all browser text messages
    - demo.html: attach agent audio tracks to <audio> elements so Gemini
    voice is actually played back in the browser
    - Transcription log now labels Gemini vs user speech clearly
    Claude-Session: https://claude.ai/code/session_011puj3DBA3pwri2yZ3VppBH
2026-06-28 Add top-view camera, fix audio and data message handling
    demo.html:
    - Split video panel into two rows: robot-eye (LiveKit) + top-view (MJPEG
    from localhost:5000/view/0) — top-view auto-refreshes every 10s
    - Subscribe and play agent audio tracks so Gemini voice is audible
    - Fix transcription labels: Gemini vs user (voice) clearly shown
    agents/livekit_gaze_agent.py:
    - data_received callback now correctly receives DataPacket object
    - asyncio.get_running_loop() instead of get_event_loop() in sync handler
    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
2026-06-28 Fix text dispatch: direct gaze engine + session.say(), proper async handling
    Root cause: generate_reply() does not inject text into Gemini Live
    (realtime/audio model) — it only works with text-based LLMs.
    Fix:
    - ctx.connect() now called FIRST so agent is in the room before
    data_received can fire
    - _dispatch_text() parses intent directly (pick/look/stop/status)
    and calls gaze engine / _look() / session.say() — bypasses
    the broken text injection path
    - _look() extracted as standalone async fn shared by function_tool
    and direct dispatch
    - on_data callback stores loop ref before going into sync context
    (avoids get_running_loop() RuntimeError from callbacks)
    - Startup greeting uses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
2026-06-28 Fix agent dispatch: explicit dispatch on token mint, better logging
    Root cause: agent was never being dispatched to the room.
    In livekit-agents, the worker registers globally but doesnt
    auto-join rooms -- LiveKit must be told explicitly via dispatch API.
    Changes:
    - demo_server.py: call lk.agent_dispatch.create_dispatch() on /token
    so agent joins room as soon as user connects
    - livekit_gaze_agent.py: register data_received BEFORE ctx.connect()
    to avoid race; print() every step so terminal shows whats happening
    - demo.html: show participant_connected events so user sees agent join
    Claude-Session: https://claude.ai/code/session_011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
2026-06-28 Fix 3 runtime errors from logs
    1. Wrong model: gemini-3.1-flash-audio-eap -> gemini-2.0-flash-live-001
    (eap model is unavailable via v1beta API)
    2. Camera stream before room connects: move publish_track call to
    start_camera_stream() invoked after ctx.connect()
    3. session.say() crashes when Gemini session fails: add _say() helper
    that falls back to _broadcast() so browser still gets the message.
    Also move run_in_executor BEFORE _say() so gaze engine starts even
    if say() throws.
    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
2026-06-28 Fix Rerun viz loop to mirror entrypoint.py exactly
    - Use engine.last_obs (not arm.get_observation() again)
    - Get u_aim/v_aim via engine._gaze_uv(focus, last_obs)
    - Pass kin= so the 3D arm sim renders in Rerun
    - Pass depth_m=engine.range_m and aim_v_offset_px=engine._aim_v_now
    - Store self._kin in _setup() for the viz call
    - Log debug instead of silently swallowing Rerun errors
    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
2026-06-28 Fix Rerun mock arm crash + Gemini Live api_version
    - Pass kin=None in mock mode (CartesianKinematics lacks get_link_transforms_chain)
    - Switch Gemini Live api_version back to v1alpha (v1beta 404s on preview models)
    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
2026-06-28 Add get_link_transforms_chain to CartesianKinematics for Rerun mock viz
    - Implements the method log_manipulation_sim3d expects
    - Returns [base, ee] chain so Rerun draws ground grid + EE axes + arm line
    - urdf_dir=None so mesh loading skips cleanly (no STL in mock mode)
    - Re-enables kin= passthrough in GazeRunner (no longer set to None for mock)
    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
2026-06-28 Fix Rerun mock mode: bypass log_manipulation_sim3d when no URDF
    log_manipulation_sim3d swallows NoneType internally so _log_arm_chain_fallback
    was never called. Now we check for urdf_dir before calling it:
    - has_urdf=True (real arm): call log_manipulation_sim3d as before
    - has_urdf=False (mock): call _log_arm_chain_fallback + _log_ground_grid directly
    _log_ground_grid draws workspace grid + wireframe target cube box in sim3d.
    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
2026-06-28 Persistent gaze engine: initialize once, query at runtime
    Replace _GazeRunner (tear-down per command) with _PersistentGaze:
    - Arm + camera + Rerun initialize once in background thread on agent enter
    - pick(query) queues new task: creates fresh CloudTracker+GazeEngine (~50ms)
    - Arm stays connected between commands — no reload delay
    - Idle loop streams camera to Rerun continuously
    - stop_task() cancels current pick but keeps arm ready
    - _stream_robot_camera and _dispatch_text updated to use agent._gaze
    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
2026-08-02 stack_mission2: object map for any YOLO class, place/stack, guest UI, resilience
    Detection & map
    - Detect and map arbitrary YOLO-World classes, not just cubes; monocular
    size/orientation via silhouette-on-table (measure_object), long-axis range
    for elongated objects, apparent-size fallback.
    - Merge map entries by POSITION (one object fires under several labels),
    expire stale entries (MAP_TTL_S), draw a real orientation only when measured.
    - publish() overlays every detection, not just the two cube trackers.
    Pick / place
    - run_mission targets the mapped (x,y); 3-stage approach (90% + small
    corrections) then eye-in-hand centering onto HAND_UV.
    - place_at / task engine: "green on red",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
2026-08-06 Add arm-profile layer + parity harness (modularization phases 0-1)
    First step toward running the pick stack on arms other than the SO-101. Nothing
    is rewired yet in the wider codebase; these are additive foundations.
    robots/profiles/ describes an arm as data instead of as literal joint indices
    scattered through the algorithms: which joint is the pan, which are the parallel
    pitch chain, which is the roll, plus the URDF, extrinsics, gripper thresholds and
    named poses. Two IK topologies are declarable ("pitch_hold" for SO-101-like arms,
    "pose" for generic 6-DOF wrists) and validate() rejects a profile that describes
    an arm incoherently, since a wrong topology drives the wrong joint.
    urdf_limi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
    [so101.py]
2026-08-06 Bridge the YOLO detection gap for arbitrary labels with a pixel tracker
    YOLO-World runs on a ~2.5 s background cycle, so between detections any label
    that is not a red/green cube had no position at all — the cubes had AnchorTracker
    to carry them, everything else went blind.
    Adds PixelTracker: a CamShift tracker over a colour-histogram back-projection,
    lazily created per label and re-tagged from each fresh YOLO box. It gives up when
    no YOLO tag has confirmed it for PIXEL_TRACK_MAX_AGE_S (8 s) or when the mean
    back-projection response inside the window falls below PIXEL_TRACK_MIN_RESPONSE,
    rather than confidently reporting a window that has drifted onto the background.
    Wired into yolo_work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
2026-08-06 Drive stack_mission2 from the arm profile instead of literals
    Replaces the hardcoded SO-101 constants with values read from
    robots/profiles/so101.py, keeping every existing name so the rest of the file is
    untouched. RAX_ARM=<name> selects a different profile.
    Moved behind the profile: the hand-eye TF, grasp/render roll, HOME and VIEW,
    HAND_UV, tip and camera offsets, joint rate cap, table height, workspace radii,
    the gripper's open/close/contact thresholds, the servo bus layout, the camera
    resolution and depth flag, the intrinsics fallback, SURVEY_TILT, and the three
    separate hardcodings of the COM4 serial port.
    Two things worth flagging:
    * Joint limits now come from the URDF rather than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
2026-08-06 Extract camera geometry, table plane and object priors into perception/
    Phase 2 of the modularization. The pixel<->world maths, the measured table
    surface and the per-class size priors were module globals plus free functions in
    stack_mission2; they are now parameterized objects the algorithms are handed.
    perception/camera_geometry.py replaces the fx/fy/cx0/cy0/T_ee_cam globals with a
    CameraGeometry built from StereoIntrinsics (already the repo's canonical
    intrinsics type) plus a CameraPose. The pose is the seam that makes the geometry
    mount-agnostic: EyeInHand composes FK(q) with the hand-eye transform, FixedCamera
    returns a constant. Localization and the object map work either way; tip_pix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
2026-08-06 Extract the pitch-holding IK into an arm-agnostic strategy
    Phase 3. _ik_hold_pitch was the last big piece of the stack that hardcoded the
    SO-101's shape: q[0] is the pan, q[1]+q[2]+q[3] is the gripper pitch, q[4] is the
    roll, written as literal indices throughout.
    manipulation/arms/ik_strategy.py puts two implementations behind one protocol:
    PitchHoldIK the same solver, generalized. For arms whose pitch joints share a
    parallel axis it slaves the last one algebraically instead of
    solving it, which is why the held pitch never drifts. Which joints
    those are now comes from the profile.
    PoseIK for arms with a real 6-DOF wrist: builds the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
2026-08-07 Extract the smooth-transit trajectory maths into manipulation/arms/motion.py
    goto_smooth's quintic S-curve is pure joint-space maths with no robot in it, but
    it sat inline in the send loop with the SO-101's per-joint velocity and
    acceleration ceilings hardcoded beside it.
    motion.py now owns the profile generation - duration solved against both the
    velocity and acceleration limits, waypoint sampling, and a rate_limit clamp - with
    no clock and no I/O, so it is testable and shared. stack_mission2 keeps the send
    loop and its real-time pacing, which is the part that genuinely needs a robot.
    The ceilings move into the profile as goto_vmax_dps / goto_amax_dps2 / goto_dt_s.
    They are per-joint beca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
    [so101.py]
2026-08-07 Extract localization and the object map into perception/ and mobility/slam/
    Phase 4, first half: the two pieces that answer "where is it" and "what is on the
    table". Both were free functions reading module globals; both are now objects the
    callers are handed.
    perception/locate.py puts the three range strategies behind one Localizer
    protocol - stereo depth, the table-plane solve, and apparent size - each returning
    a Fix that says which method answered, because "how do we know" matters when the
    arm is about to drive at the answer. Depth-absent is the normal path on this rig,
    so the chain degrades without complaint. The elongated-object long-axis branch
    moves across intact: apparent-size rangi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
2026-08-07 Add ApproachConfig, a second arm profile, and the guide for adding one
    Phase 5 (config) and Phase 6 (proving the seam).
    manipulation/approach/ collects every approach tunable into one ApproachConfig,
    replacing the two competing idioms for the same job - `global X` rebinds and the
    `X[0]` one-element-list trick - and gives get/set by knob name with bounds. That
    name surface is a public API: an autotuner drives right_trim_cm and back_cm by
    name through the HTTP routes and the UI reads the same names from /status, so the
    wire names and units are unchanged and the seven tuning routes are now thin shims.
    Bounds are the routes' own, not the tuner's narrower walking range, since
    tightening them wou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
2026-08-07 Fill in the package public surfaces
    The extracted modules were importable only by full path. Each package's __init__
    now names what it exports and why, so `from perception import CameraGeometry,
    ObjectMeasurer` works and the layout is discoverable without reading every file.
    perception/ and mobility/slam/ were docstring-only stubs whose text already
    described the intended contents; they are filled in rather than replaced.
    mobility/slam's docstring now says plainly that what lives there is deliberately
    not SLAM - an eye-in-hand camera's pose is computed from the servo angles, not
    estimated - so nobody goes looking for a pose graph that was never meant to exist.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
2026-08-07 Extract the final centring servo to manipulation/approach/visual_center.py
    The last piece of the approach that is genuinely reusable rather than
    orchestration. It reaches the arm through CenteringOps, a seven-method protocol -
    rotate the base, reach to a point, report the tip, find the object - so it works
    for any arm with those abilities rather than only this one.
    The property worth preserving is that its gains are MEASURED, not modelled. Before
    servoing it makes one small probe move per axis and measures how many pixels the
    object shifted. A hand-eye transform carrying roll or yaw error can invert the raw
    pixel signs, so a hand-derived gain drives the loop the wrong way and stalls;
    probin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
2026-08-07 Solve the localization knobs from FK ground truth instead of dialling them
    push_out_cm, range_scale and bearing_deg were never preferences. Each is a human
    turning a dial until grasps stopped missing - a compensation for a systematic error
    nobody had measured. That is why they needed retuning whenever the mount shifted,
    and why an autotuner existed to walk them around at all.
    They can be computed, because the arm generates its own ground truth: while the
    gripper holds an object, forward kinematics says exactly where that object is.
    Present it across a spread of radii and bearings, localize it normally, and the
    difference is the error - measured everywhere you care about, no ruler, no
    judgem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
2026-08-08 Fix three defects found by running the server on real hardware
    Two were regressions I introduced; the third was latent and the new test found it.
    1. The 3D viewer lost its meshes. lerobot's mesh loader takes a DIRECTORY and looks
    for a file named exactly "robot.urdf" in it. Pointing kinematics at this repo's
    URDF moved that directory to RAX/SO101, which has the assets but not that
    filename, so /urdf logged "No robot.urdf in directory". The mesh directory is now
    a profile field (mesh_dir) rather than being inferred from the kinematics object,
    since a mesh loader's filename convention is not something an arm should have
    assumed for it. SO101/robot.urdf is added as a copy - v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
    [robot.urdf]
2026-08-10 Derive an arm's reach, pitch table and IK seeds instead of hand-measuring them
    Extraction alone was moving custom code, not removing it. DEFAULT_GRASP_PITCHES was
    just as hand-measured after the refactor as before: a comment recording "90deg ->
    30.8cm, 70 -> 36.4 ... 0 -> 47.8" that somebody obtained by driving the robot, plus
    reach limits, plus five IK seeds added one at a time while watching an arm fail.
    None of it transfers to a different arm.
    All of it is a derivable property of the URDF and the solver, so
    manipulation/arms/workspace.py derives it: probe the (radius, height, pitch) space
    with the arm's own IK and keep what solved.
    Verified against the hand-measured numbers it replaces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
2026-08-10 Derive grasp height, centring tolerance, approach trim and merge radius
    Four more hand-dialled constants replaced by the geometry or measurement that
    answers them. Each was tuned on one object at one range and silently wrong
    elsewhere.
    PICK_GRASP_Z = 1.5cm -> grasp_height(object_h). Grips below the object's
    mid-height so it cannot pivot out of the jaws, clear of the table. The fixed value
    was right for the 5cm cube it was tuned on and wrong for the rest of the class
    table: on a 0.9cm cell phone it closes ABOVE the object, and on a 23cm bottle it
    grips the very bottom - the least stable place to hold one. Derived, those become
    0.4cm and 9.2cm. hover_height additionally clears the object's TO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
2026-08-11 Wire the derived parameters into the running server, and clean up
    Finishes the objective: the architecture was generic, the running behaviour was
    still the hand-tuned constants. Now the constants are fallbacks and the derivations
    drive.
    grasp height derived from the object's measured height (wired earlier)
    align tolerance a fraction of the object's apparent size, computed per target,
    instead of 40px meaning 15% of the object at 10cm and 69% at 45cm
    approach trim computed from the field of view and the closest approach range,
    instead of 5cm which pushes the object out of frame at 8cm
    merge radius adopted from the map's own measu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
    [so101.py]
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2026-08-22 Move the library under src/rax, demote the demos, and make it installable
    Six top-level packages named perception/, models/, common/, control/, robots/
    and mobility/ collide with the world the moment anyone installs this, and
    `import models` is a namespace landmine. They now live under src/rax/, imports
    rewritten across every file including the two 5,000-line servers.
    REPO_ROOT walks up for a project marker instead of counting directory levels —
    the count already changed once with this move, and a silently wrong root turns
    every URDF path into a confusing "file not found" far from the cause.
    The library is the product; everything built on it moves to examples/ —
    mission_server (the pic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
    [robot_client.py, so101.py]
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2026-08-23 Clear the publishing debris, and ship the SO-101 URDF in the wheel
    `--arm so101` was broken for anyone who installed the package. The profile resolved
    `SO101/so101_new_calib.urdf` against the repo root, but SO101/ sat outside src/, so
    setuptools never put it in the wheel; installed, urdf_path fell through to a
    cwd-relative path that only exists if you happen to be standing in the repo. CI did
    not catch it because it smoke-tests head_mono and mock, and neither has a URDF.
    SO101/ moves into the package, urdf_path and mesh_path try a new PACKAGE_ROOT before
    REPO_ROOT (the same directory in a clone, different ones after pip install), and the
    URDF ships as package data. The 17 MB of STL meshes d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
    [Wrist_Roll_D405_Holder - SO_ARM100_Wrist_Roll_2 v4.stl, base_motor_holder_so101_v1.stl, base_so101_v2.stl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]
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2026-08-27 Point the survey camera at the table, and put its pitch on a dial
    The survey localized from a pose whose camera sat 3 degrees ABOVE horizontal. Measured
    across a full pan sweep against MIN_TABLE_INCIDENCE, that covered 40% of the reachable
    table and nothing whatsoever inside 30cm:
    radius 18 22 26 30 34 38 42 cm
    covered 0 0 0 9 82 100 100 %
    So near objects were never in a survey frame at all, and what the map held for them came
    from whatever grazing view clipped the frame edge — where a 2.3 degree hand-eye error
    (21px at fx=517) is amplified about 8x by the 1/(w/2fx + |dir_z|) range solve. A real
    failed pick showed the whole loop: map says 45.7cm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
    [so101.py]
2026-09-08 Fix reach, task routing, grasp offset and map ghosts; add a vision-model assist
    Ten fixes found by running the rig, each pinned by tests. 390 tests, up from 223.
    REACH. The jog loop clipped the tip radius at a hardcoded 0.42m while the profile
    claimed 0.55 and the arm measures 0.47, so jogging out stopped 5cm short with
    nothing logged and looked like the arm refusing to extend. Measured the envelope
    two independent ways (workspace prober, and an IK scan) and put it in the profile
    as reach_grasp_max_m, with the pitch dependence recorded: 47cm flat, 34cm at the
    75 degree grasp pitch tried first.
    TASKS. "red on green" typed into the query box read as a vocabulary, so Start ran
    a plain pick an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
    [so101.py]
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2026-09-27 Put the object where it was asked for, and measure the grasp honestly
    THE PLACE BUG, which is the one that was costing centimetres. The pick deliberately
    stands the fingertip off the object -- grasp_right_cm to its right so the near finger
    passes it instead of shoving it, grasp_back_cm forward -- and that is what makes the
    grasp work. The consequence was never carried through: a held object therefore sits
    ~2.8cm from the fingertip, and every release drove the FINGERTIP to the destination and
    opened. Measured live: green at (26.6,+1.7), grasp point (28.8,-0.2). The operator
    measured the result independently as "you missed the drop target by like 4-5cm".
    The fix is not a new constant. The obj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
    [so101.py]
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2026-09-30 SO-101: reconnect the wrist camera after an OAK-D crash; a black overhead frame is no view
    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
    [so101.py]
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2026-09-30 One process, two UIs: the old control panel on :8484, tubes on :8486
    Like the mission server did, one process opens the arm once and serves both
    pages; a job from either holds the arm until done. examples/server.py starts
    it, examples/run.ps1 launches it detached.
    examples/rig_app.py: Rig (shared arm, log, job lock, camera loop, polar
    teleop) and App (a UI on it: live view with its own overlay, 3D view,
    stop/reset/home/relax, joystick routes, room camera).
    The general UI is the original admin.html (with joystick.js and viewer3d.js)
    restored from git, backed by rax.pick: YOLO-World query and presets, Start
    (pick what's in view, 90deg or flat), scan to 2D map, click to go on top,
    place / pic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
    [base.py, so101.py, x250.py]
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2026-09-30 Faster pick with fewer adjustments; a held cube no longer reads as "two"
    - Base turns per step are error / measured gain, capped at 15deg (aim),
    6deg (approach), 5deg (trim) instead of 5 / 2.2 / 1.8, and the aim now
    finishes the sideways correction (40px, was 150). A 138px error took six
    approach steps before.
    - Straight-down moves take one IK waypoint per 2cm and settle only at the
    end, instead of 8 small stop-and-settle moves per descent.
    - An approach whose reach cannot be solved at the look angle hands over to
    the stand-up after two tries instead of nudging the base for 12 steps.
    - If the object drops out of view on the way in, the wrist tilts down to
    find it again before giv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
    [base.py, so101.py, x250.py]
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
